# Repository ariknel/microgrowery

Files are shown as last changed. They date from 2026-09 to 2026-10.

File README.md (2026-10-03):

<p align="center">
  GrowBox Cabinet
</p>

<h1 align="center">🌱 GrowBox</h1>

<p align="center">
  Open-source USB-C powered smart microgrowery<br/>
  ESP32-S3 hub · 87W LED panel · WiFi dashboard · Camera streaming · USB-C PD
</p>

<p align="center">
  
  
  
  
</p>

---

## Table of Contents

- [Overview](#overview)
- [Cabinet](#cabinet)
- [PCB Boards](#pcb-boards)
- [Web Dashboard](#web-dashboard)
- [Camera Feed](#camera-feed)
- [Features](#features)
- [Grow Schedule Recommendations](#grow-schedule-recommendations)
- [Build & Technical Reference](BUILD.md)
- [Bill of Materials](BOM.md)
- [License](#license)

---

## Overview

GrowBox is a fully custom USB-C powered microgrowery designed to fit under a desk. The controller drives an 87W warm white LED grow panel, controls intake and exhaust ventilation fans, monitors temperature and humidity, streams a live camera feed, and serves a local web dashboard — all from a single USB-C cable.

Everything is custom designed: four separate PCBs, ESP32-S3 firmware in bare C using ESP-IDF, and a self-contained HTML dashboard served directly from the microcontroller.

<p align="center">
  Cabinet open showing plants
</p>

**Key specs at a glance:**

| Parameter | Value |
|---|---|
| Input power | USB-C PD 20V via FUSB302 |
| Max LED power | 87W (80× warm white LEDs) |
| LED panel | 4× boards in a grid |
| Cabinet size | 600 × 450 × 720mm (external) |
| MCU | ESP32-S3 bare SoC, 8MB NOR flash |
| Connectivity | WiFi 802.11 b/g/n, mDNS `growbox.local` |
| Environment sensor | AHT20 temperature + humidity |
| Camera | ESP32-CAM MJPEG stream |
| Fan control | 2× PWM fans, independent speed |

---

## Cabinet

Constructed from 12mm MDF, interior walls painted white for light distribution. A DIY activated carbon filter with a 120mm exhaust fan handles odor control.

<p align="center">
  Cabinet front closed
  &nbsp;&nbsp;
  Cabinet front open
</p>

<p align="center">
  Interior top view showing LED panel
  &nbsp;&nbsp;
  Interior side view showing fans and filter
</p>

```
External:   600 × 450 × 720mm  (W × D × H)
Internal:   576 × 426 × 696mm  (external minus 2× 12mm MDF wall per axis)
Fan intake:  120mm, bottom-right panel
Fan exhaust: 120mm, top-right panel
Carbon filter: 3D printed housing, 80mm activated carbon bed, inline on exhaust
```

<p align="center">
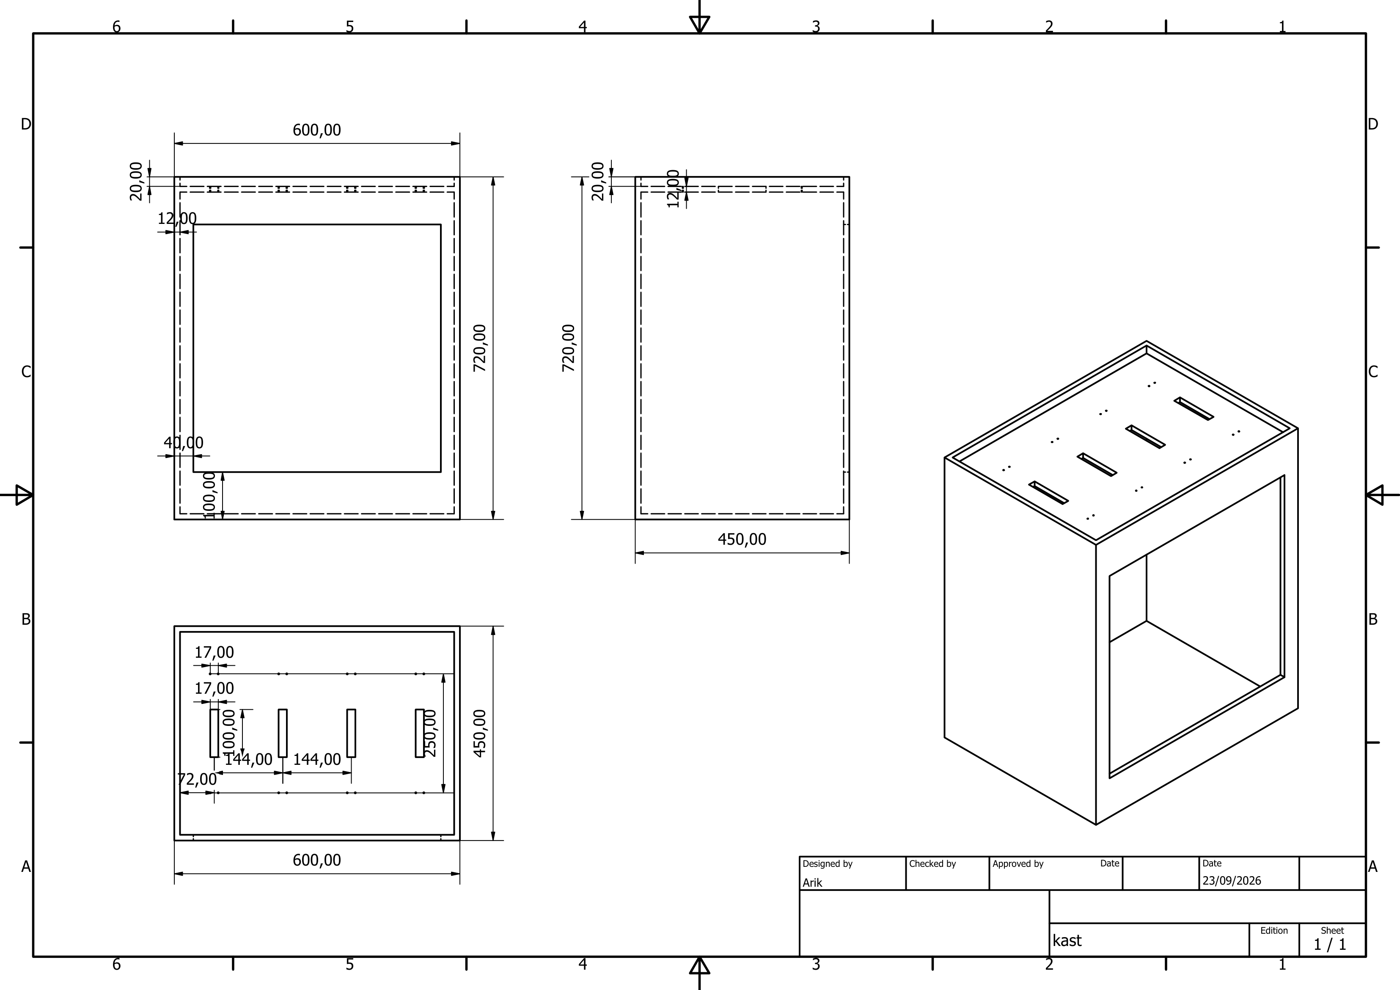
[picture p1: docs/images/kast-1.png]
Cabinet technical drawing
  
</p>

---

## PCB Boards

Four custom PCBs, designed in KiCad and manufactured at JLCPCB. Full GPIO pinout, connector tables and component values live in [BUILD.md](BUILD.md).

### 1. Main Hub Board

The brain of the system — ESP32-S3, FUSB302 PD sink negotiation, AP63203 3.3V regulator, 8MB flash, and JST connectors for every other board and peripheral.

<p align="center">
  Hub board top
  &nbsp;&nbsp;
  Hub board bottom
</p>

<p align="center">
  Hub board KiCad 3D render front
  &nbsp;&nbsp;
  Hub board KiCad 3D render back
</p>

<p align="center">
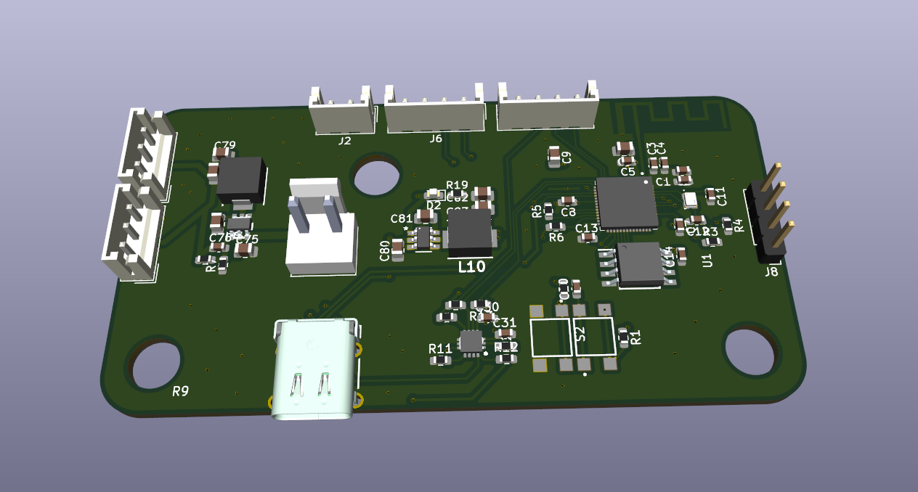
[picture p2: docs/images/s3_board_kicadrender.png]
Hub board KiCad 3D render, angled view showing USB-C, connectors and the ESP32-S3 module
  
</p>
<p align="center">
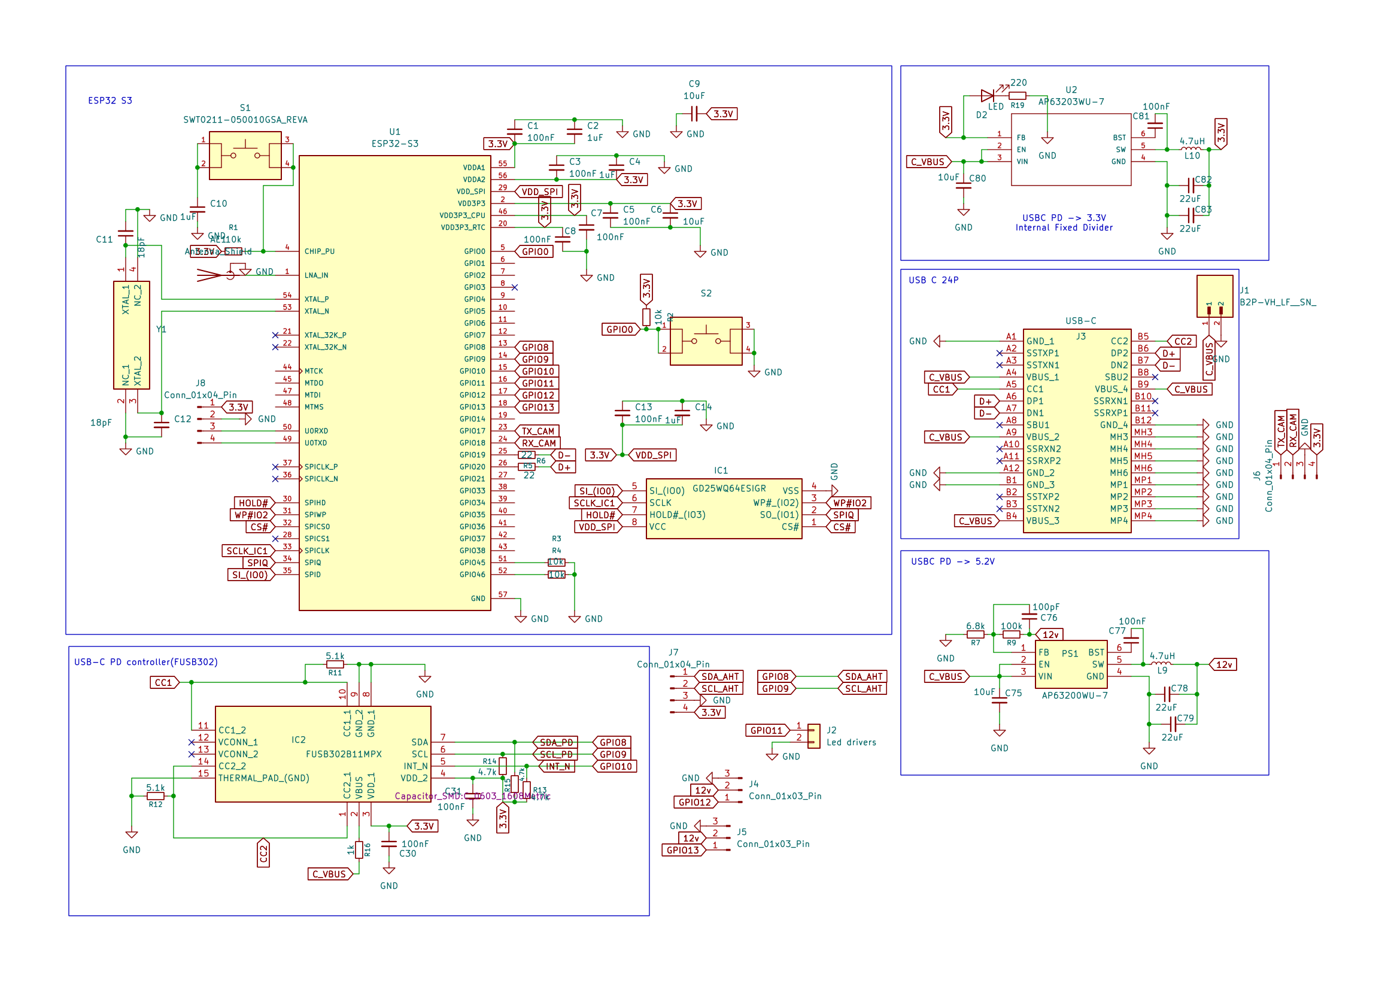
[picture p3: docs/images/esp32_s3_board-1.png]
Hub board full schematic — ESP32-S3, FUSB302 PD, USB-C, buck regulators
  
</p>

### 2. LED Driver Board

One of four identical boards — 4× TX6120 constant-current drivers each, powering 4 strings of 5 LEDs (~21.8W per board, ~87W across all four).

<p align="center">
  Driver board top assembled
  &nbsp;&nbsp;
  Driver board bottom
</p>

<p align="center">
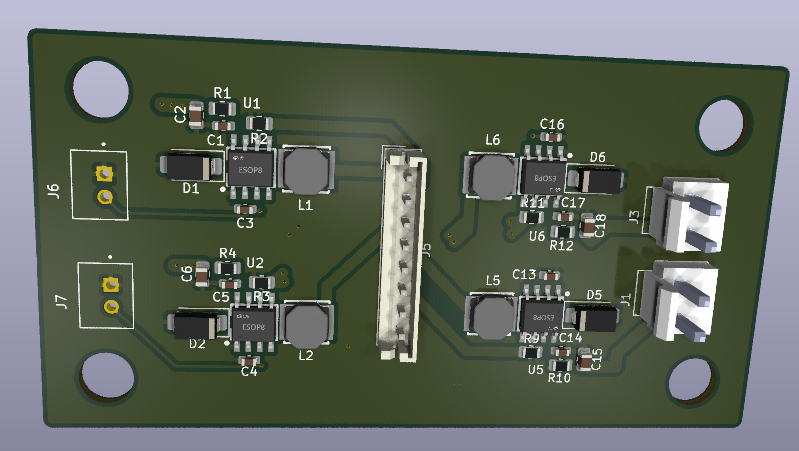
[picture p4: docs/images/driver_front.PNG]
Driver board KiCad 3D render
  
  &nbsp;&nbsp;
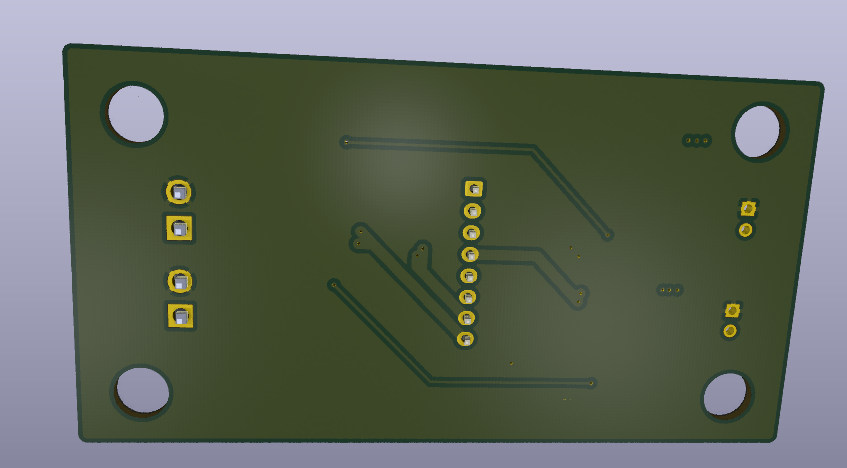
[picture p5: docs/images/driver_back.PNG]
Driver board KiCad 3D render back
  
</p>

<p align="center">
  All 4 driver boards side by side
</p>

### 3. LED Panel Board

One of four identical boards — 20× XL-3030WWC-1W-3V warm white LEDs each (80 total), single-layer FR4 with an aluminum bottom layer for heat spreading.

<p align="center">
  LED board not powered
  &nbsp;&nbsp;
  LED board powered on
</p>

<p align="center">
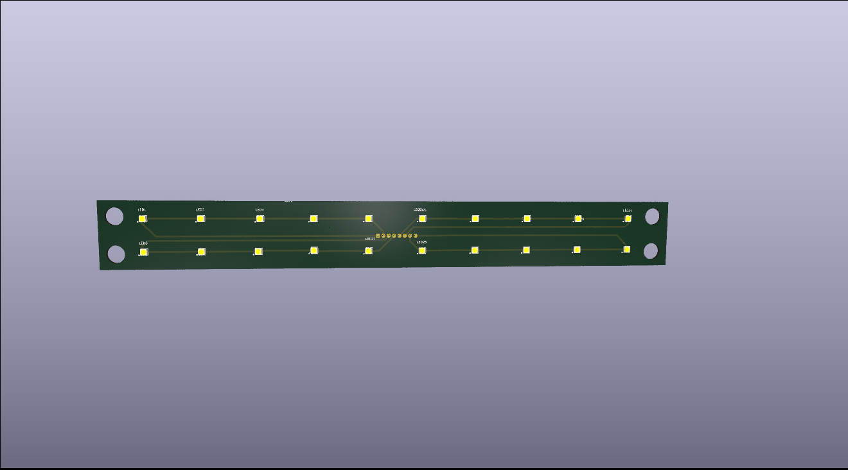
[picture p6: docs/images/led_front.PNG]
LED board KiCad 3D render
  
  &nbsp;&nbsp;
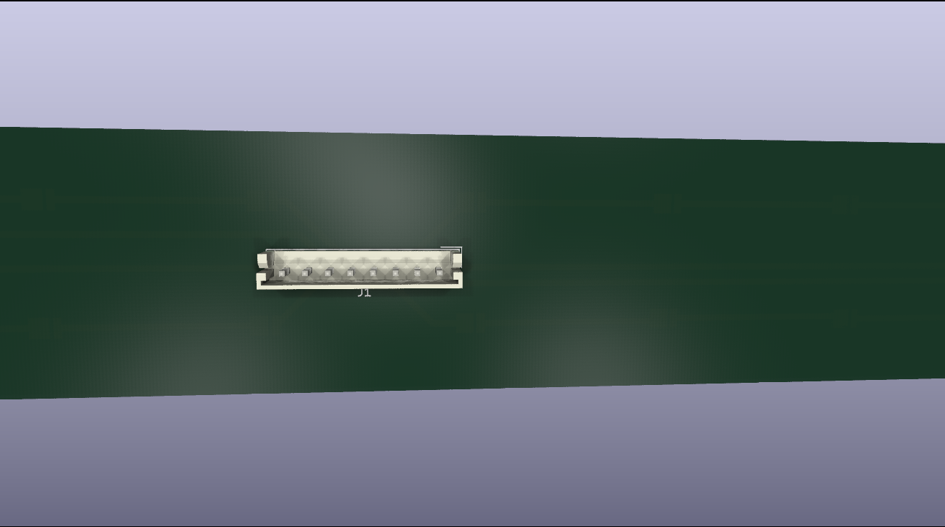
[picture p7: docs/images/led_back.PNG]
LED board back showing copper pour and aluminum bottom layer
  
</p>

<p align="center">
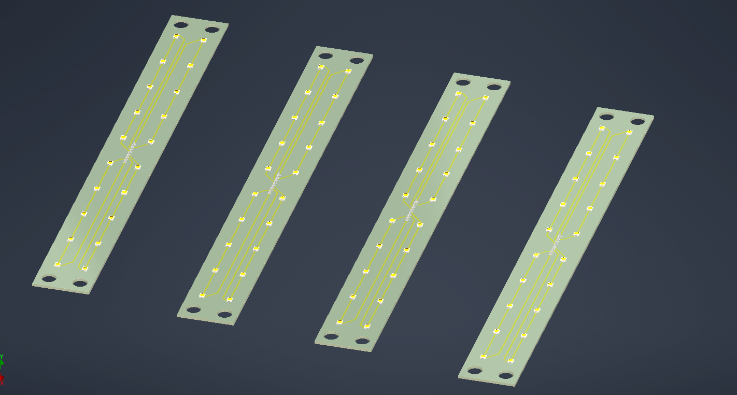
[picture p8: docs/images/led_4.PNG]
All 4 LED boards assembled in 2x2 arrangement
  
</p>
<p align="center">
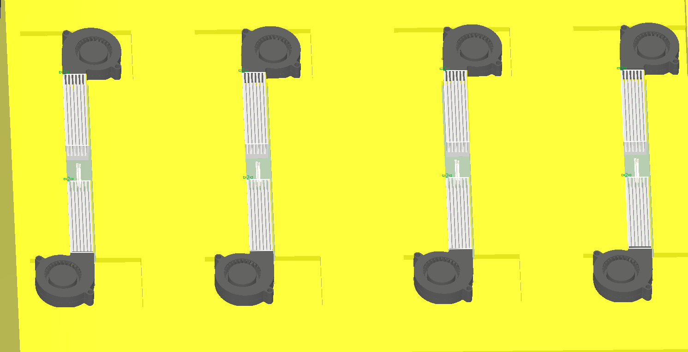
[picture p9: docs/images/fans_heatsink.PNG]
8x 5015 24dB blower fans, one per heatsink, each on its own short duct — 2 fans per LED board, 4 boards total
  
</p>

At 21.76W per board on an 85×55mm footprint, passive cooling alone isn't
enough to sustain full brightness — each board got 2× extruded aluminum
heatsinks, each with its own dedicated 5015 blower (24dB) on a short
individual duct: 8 fans total across the 4 boards, one per heatsink rather
than one fan shared across both. Estimated safe continuous power: ~4W bare
board, ~11W with heatsinks only, full 87W-panel brightness (100%) with the
fans running. Full thermal model and assumptions:
[BUILD.md#thermal-analysis--led-board-cooling](BUILD.md#thermal-analysis--led-board-cooling).

<p align="center">
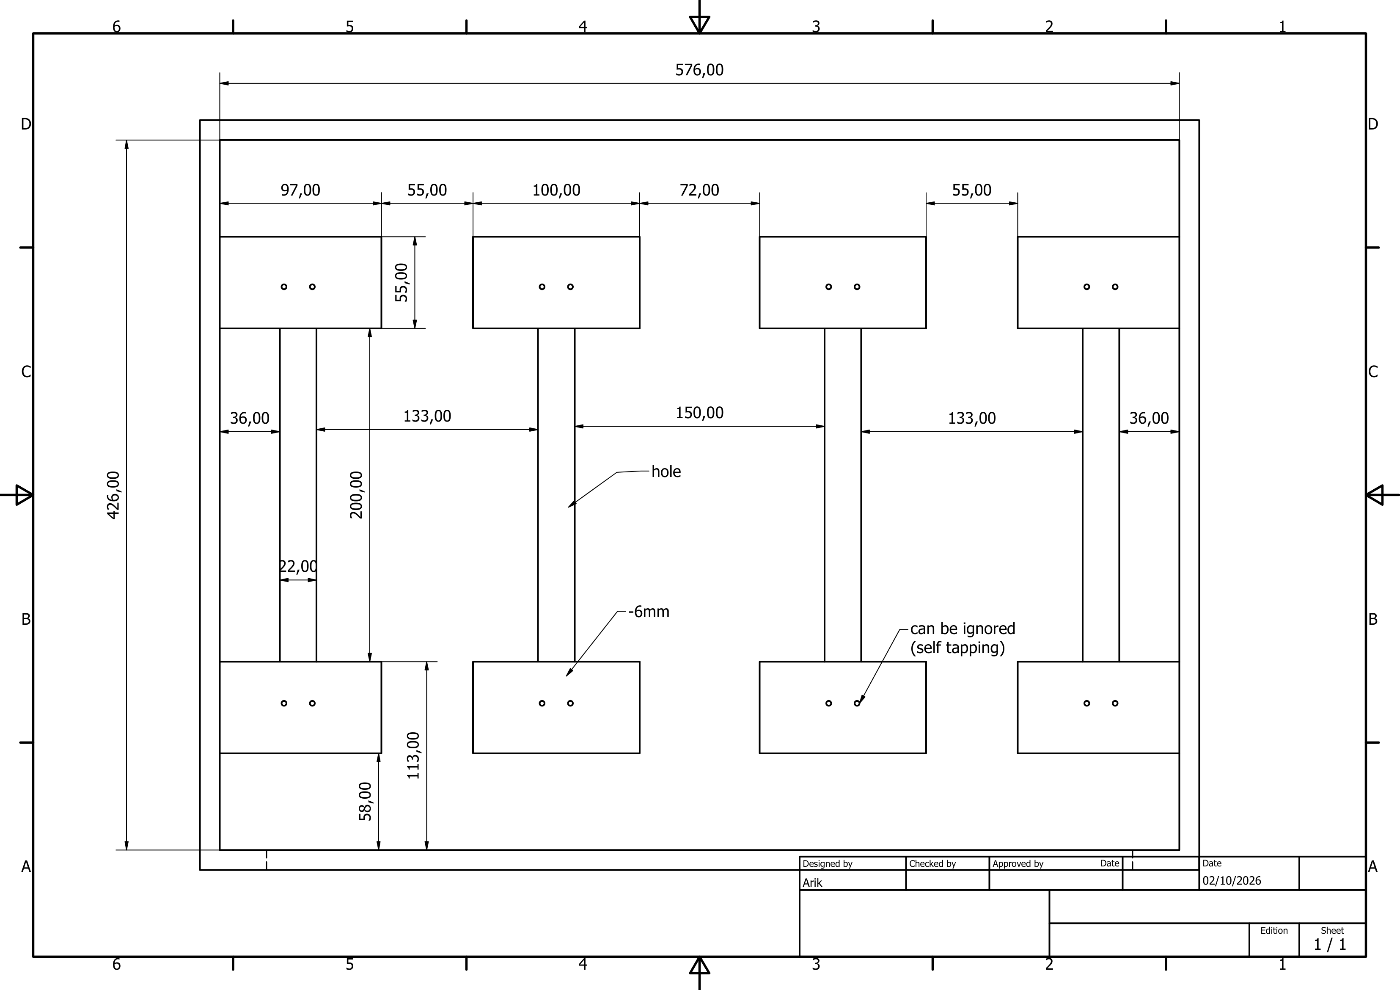
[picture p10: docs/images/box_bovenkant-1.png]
Top panel technical drawing — 576x426mm, 4 columns of 2 heatsink mounting pads each
  
</p>

The 8 fan cutouts aren't cut into the top panel drawing yet. Proposed
placement: centered on each of the 8 existing heatsink mounting pads shown
above (one column per LED board, top and bottom pad = top and bottom
heatsink), sized to a generic 50×50mm blower footprint — the real 5015's
exact mounting pattern still needs to be confirmed against its datasheet
before cutting. Fan control itself is a separate dedicated board — see
[fan_controller/](fan_controller/).

### 4. Sensor Board

A minimal standalone board carrying just the AHT20 temperature/humidity sensor, connected to the hub over a 4-pin I2C cable. Mounted mid-height on the cabinet wall, away from heat sources, for accurate ambient readings.

<p align="center">
  Sensor board top
  &nbsp;&nbsp;
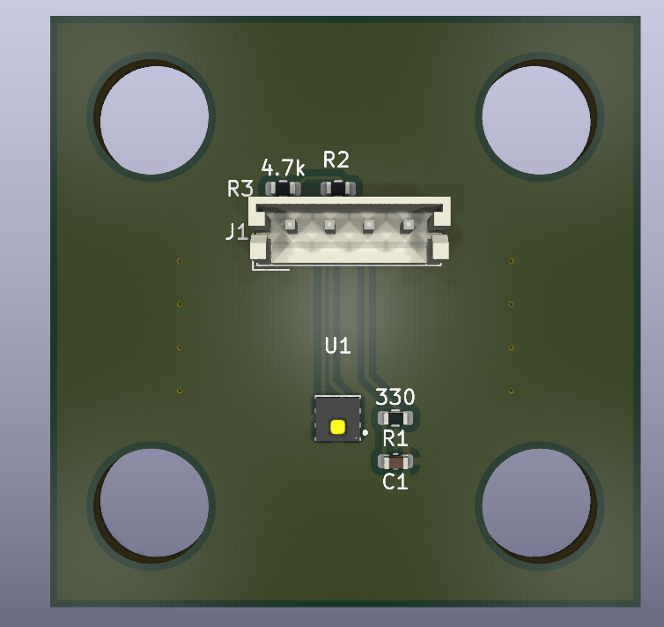
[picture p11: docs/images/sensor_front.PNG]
Sensor board KiCad 3D render
  
</p>

---

## Web Dashboard

A single self-contained HTML file served directly from ESP32-S3 flash — no internet connection required. Access it at `http://growbox.local` from any device on the same WiFi network.

<p align="center">
  Full dashboard screenshot
</p>
<p align="center">
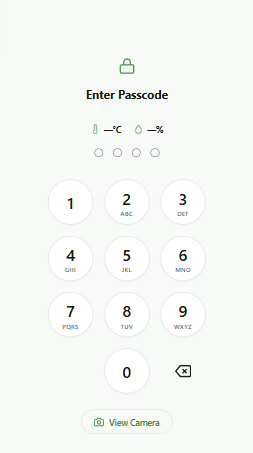
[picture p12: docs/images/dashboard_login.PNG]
Dashboard Mobile Login Page
  
</p>

<p align="center">
  Dashboard on mobile
  &nbsp;&nbsp;
  Dashboard with camera feed active
  &nbsp;&nbsp;
  Dashboard light schedule panel
</p>

| Panel | Description |
|---|---|
| Camera feed | Live MJPEG stream from ESP32-CAM, tap to enable/disable |
| Temperature / humidity | Live readings, session min/max |
| LED brightness | Slider 0–100% with live watt estimation |
| Fan control | Independent intake and exhaust sliders |
| Light schedule | On/off time pickers, 24h visual timeline, enable toggle |
| System status | WiFi RSSI, uptime, PD status, free heap, grow day counter |
| Power summary | Estimated total wall draw |

---

## Camera Feed

The ESP32-CAM mounts on the interior cabinet wall via a 3D printed bracket, angled downward to cover the full plant canopy, connected to the hub over a 4-wire UART cable. It streams on demand only — power-saving start/stop commands are sent as the dashboard opens and closes the feed. Protocol details in [BUILD.md](BUILD.md).
<p align="center">
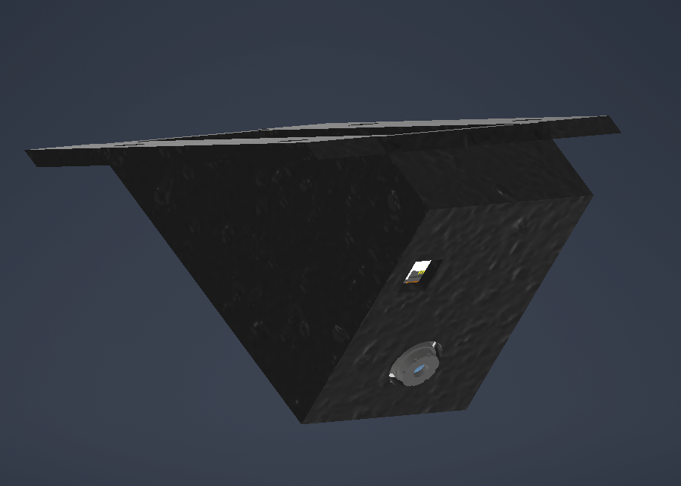
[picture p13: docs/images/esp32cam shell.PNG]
ESP32-CAM Mount CAD
  
</p>
<p align="center">
  ESP32-CAM mounted inside cabinet
</p>

<p align="center">
  Camera feed showing plants
</p>

---

## Features

- **USB-C PD negotiation** — full FUSB302 driver written from scratch in C. Requests 20V fixed PDO, handles Source_Capabilities, Accept, PS_RDY. Retries every 30 seconds on failure, renegotiates on cable disconnect
- **LED brightness control** — 0–100% PWM via LEDC at 25kHz. Smooth 5-minute sunrise/sunset ramp on schedule transitions. Persisted to NVS
- **Light schedule** — configurable on/off time, SNTP sync, Europe/Brussels timezone, grow day counter from first boot
- **Fan control** — independent intake and exhaust speed 0–100%
- **Environment monitoring** — AHT20 polled every 10 seconds, session min/max for temperature and humidity
- **Camera integration** — ESP32-CAM sends IP over UART on boot, hub proxies MJPEG to browser on demand
- **Web dashboard** — self-contained single HTML file, mobile responsive, no internet dependency
- **WiFi provisioning** — SoftAP captive portal on first boot, saves credentials to NVS, connects automatically after
- **mDNS** — accessible at `growbox.local`, no IP address needed

---

## Grow Schedule Recommendations

| Crop | Light on | Light off | Hours | Brightness |
|---|---|---|---|---|
| Seedlings (all) | 06:00 | 22:00 | 16h | 40% |
| Vegetative cannabis | 06:00 | 00:00 | 18h | 70% |
| Autoflower full cycle | 06:00 | 00:00 | 18h | 75% |
| Photoperiod flowering | 08:00 | 20:00 | 12h | 85% |
| Peppers / chili | 06:00 | 22:00 | 16h | 65% |
| Herbs / lettuce | 06:00 | 22:00 | 16h | 55% |
| Microgreens | 06:00 | 22:00 | 16h | 45% |

Power draw at each brightness level: see [BUILD.md](BUILD.md#power-budget).

---

## More

- **[BUILD.md](BUILD.md)** — GPIO pinout, wiring, connectors, NVS config, task structure, project layout, and build/flash instructions
- **[BOM.md](BOM.md)** — parts list and cost breakdown

---

## License

MIT License — see [LICENSE](LICENSE) file.

---

<p align="center">
  Made by Arik · IoT & Electronics Engineering Student · Belgium
</p>

<p align="center">
  Plants growing inside the cabinet
</p>

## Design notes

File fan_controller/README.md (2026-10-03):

# GrowBox Fan Controller

Arduino Nano sketch, independent of the ESP32-S3 hub and ESP32-CAM — see
[../BUILD.md#thermal-analysis--led-board-cooling](../BUILD.md#thermal-analysis--led-board-cooling)
for why the LED heatsinks need active cooling in the first place, and
[../README.md](../README.md) for the cabinet-level overview.

## What it does

4 independent zones, one per LED board. Each zone has its own NTC
thermistor — mounted directly on that board's PCB, not on a heatsink, so
it reads that specific board's temperature rather than general cabinet
airflow — and its own MOSFET switching that board's 2 fans together. A
board running hotter than the other 3 only speeds up its own 2 fans, not
all 8; each board's cooling is independent of the others.

Runs standalone on purpose: fan cooling keeps working even if the hub
reboots, the camera hangs, or WiFi is down — none of that affects this
board, which shares no pins or power with either. Cooling doesn't depend
on the hub hearing from it either — see "Telemetry to the hub" below.

## Telemetry to the hub

Every `REPORT_INTERVAL_MS` (2s), the Nano sends one line over its
hardware Serial (pins 0/RX, 1/TX) to the hub's `J14` UART0 debug header:

```json
{"temps":[23.4,25.1,22.8,24.0],"duty":[90,0,120,255]}
```

**Needs a voltage divider — the Nano is 5V logic, the ESP32-S3's GPIOs
are 3.3V max.** Don't wire Nano TX straight to the hub's RX pin.

```
Nano TX ---[10k]---+--- hub RX (J14)
                    |
                  [15k]
                    |
                   GND
```

`5V × 15k/(10k+15k) = 3.0V` at the junction — safely above the ESP32's
logic-high threshold (~2.48V) and comfortably under its 3.3V max. The
divider's output impedance (~6kΩ) is irrelevant against a GPIO's input
capacitance at 9600 baud, so no signal integrity concern either.

A faulted sensor reports as `null` rather than a made-up number. This is
**send-only** — the Nano's RX isn't wired to anything, and the hub never
talks back. Nothing about fan control depends on the hub receiving this;
it's read-only visibility, not a control input. Unplug it before
re-uploading the sketch over USB, same as unplugging anything else wired
to pins 0/1.

The hub parses this in `firmware/main/uart_fan.c` and stores it in
`g_state.fan_ctrl_*`, exposed read-only on `GET /api/status` under
`fan_controller`, and shown on the dashboard's "LED Cooling" card
(protected, after login — not on the public lock-screen preview). A
`null` temp entry shows as "fault" instead of a number; the card shows an
"offline" notice until the first line has ever arrived (it doesn't go
back to offline if the Nano later stops sending — no staleness timeout).

## Fan curve (tune these against a real thermocouple)

| Board temp | That board's 2 fans |
|---|---|
| < 35°C | off |
| 35°C – 55°C | ramps 35%–100% |
| ≥ 55°C | full speed |
| that zone's sensor open/shorted | that zone fails to full speed; other 3 zones unaffected |

Thresholds are `#define`s at the top of `fan_controller.ino` — the
35°C/55°C numbers are starting points, not measured values; see the
thermal analysis in BUILD.md for why (no datasheet thermal-resistance
data exists for these exact parts, so nothing in that chain is lab
measured yet).

## Noise

Each 5015 blower is rated ~24-28dB. Sound pressure from N identical
incoherent sources adds `10*log10(N)` dB, so all 8 fans (4 boards × 2
each) at full speed simultaneously is roughly a 9dB bump over one fan
alone — about **33-37dB combined**, treating all 8 as equidistant (a
rough worst-case estimate, not a measurement). Because the 4 boards share
the same dashboard brightness setting, they'll usually run close to the
same temperature and ramp up together in practice, even though each
zone's speed is computed independently — the "independent zones" design
is mainly about catching the board that's hotter than the others (worse
airflow, a bad thermal pad, etc.), not about normal operation being wildly
uneven. At low brightness all 4 zones stay off or quiet.

## Wiring (×4, one set per zone)

<p align="center">
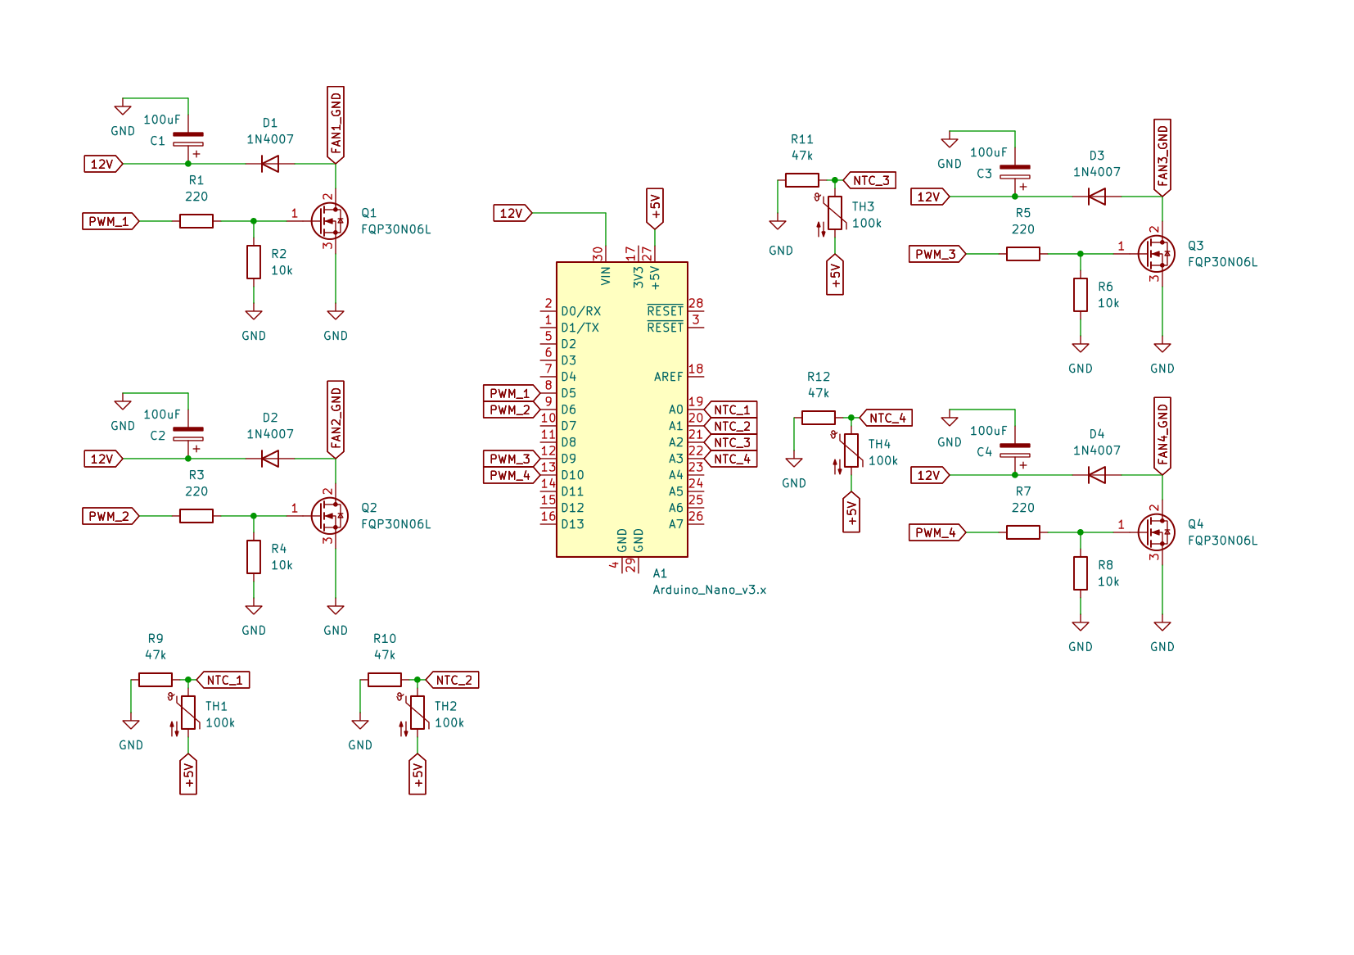
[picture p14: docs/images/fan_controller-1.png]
Fan controller schematic — Arduino Nano, 4x NTC divider + 4x MOSFET switching channel
  
</p>

```
+5V ---[TH: 100k NTC]---+---[R: 47k]--- GND      (NTC on the LED board's own PCB)
                        |
                        Nano Ax

Nano PWM pin ----------- MOSFET gate (direct — FQP30N06L is logic-level, no series resistor)
                         gate --[10k pulldown to GND]
MOSFET source -> GND
MOSFET drain  -> FANn_GND (that board's 2 fans' common return)
12V ---[220R]--+-- 1N4007 (cathode) -- FANn_GND     (snubber/flyback, clamps the
               |                                     switching spike back toward
             [100uF to GND]                          the rail instead of across the MOSFET)
Fans' + -> 12V rail (same one already on the main hub board)
```

| Zone (board) | NTC pin | MOSFET gate pin | Snubber R / D / C | Gate pulldown |
|---|---|---|---|---|
| 1 | A0 (NTC_1) | D5 (PWM_1) | R1 220Ω / D1 1N4007 / C1 100µF | R2 10k |
| 2 | A1 (NTC_2) | D6 (PWM_2) | R3 220Ω / D2 1N4007 / C2 100µF | R4 10k |
| 3 | A2 (NTC_3) | D9 (PWM_3) | R5 220Ω / D3 1N4007 / C3 100µF | R6 10k |
| 4 | A3 (NTC_4) | D10 (PWM_4) | R7 220Ω / D4 1N4007 / C4 100µF | R8 10k |

NTC divider resistors: R9 (zone 1), R10 (zone 2), R11 (zone 3), R12
(zone 4), all 47kΩ. MOSFETs: Q1–Q4, FQP30N06L (TO-220, logic-level gate —
safe to drive straight from the Nano's 5V PWM output, which is why there's
no gate series resistor in this design).

Keep this board-to-pin mapping consistent with how the boards are
physically labeled in the cabinet — otherwise "board 3 running hot" on
the serial log points at the wrong board.

The gate pull-down on each MOSFET matters: without it, that gate floats
during Nano power-on/reset (before `setup()` runs) and can sit in a lossy
partially-on state that heats up the MOSFET itself — not just a lost few
hundred ms of cooling. The 220Ω/1N4007/100µF network per channel clamps
the inductive switching spike from the fan motor back toward the 12V rail
(through the resistor, which limits clamp current) instead of letting it
ring across the MOSFET's drain-source junction, and the 100µF cap locally
decouples that channel's share of the 12V rail.

NTC part: HNTC-104F3950FB, 100kΩ @25°C, B=3950, ±1% ([LCSC C52204613](https://lcsc.com/product-detail/C52204613.html)),
paired with a 47kΩ series resistor — update `SERIES_RESISTOR_OHMS` in the
sketch if the real build ends up using a different series value. If you
ever swap to a different NTC part, double-check its Beta rating before
reusing these defaults; a wrong Beta/R25 shifts the whole curve without
giving any obvious sign that it's wrong.

## Flashing

Stock Arduino IDE, board "Arduino Nano", no external libraries. Open
`fan_controller.ino` and upload — same as any Nano sketch.

## Known gaps

- Thresholds are unverified placeholders — needs real thermocouple
  validation on each board, same caveat as the rest of the thermal
  analysis this design is based on.
- No tachometer feedback (fans' 3rd wire, if present, isn't read) — the
  controller can't detect a stalled or disconnected fan on a given zone,
  only react to that zone's temperature.
- An NTC mounted on the PCB (rather than on the heatsink itself) reads
  board temperature, which tracks junction temperature more directly but
  lags heatsink temperature slightly — fine for this fan curve's purpose,
  worth knowing if you ever compare readings against the heatsink-surface
  numbers in the BUILD.md thermal analysis.

Schematic source: [docs/Schematics/fan_controller.pdf](../docs/Schematics/fan_controller.pdf).

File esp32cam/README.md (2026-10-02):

# GrowBox Camera Firmware

ESP-IDF firmware (bare C, no Arduino) for the common AI-Thinker ESP32-CAM
board — the camera half of the [GrowBox](../README.md) build. Talks to the
hub over a dedicated UART link; the hub proxies the stream to the
dashboard. Same build method as the hub firmware: Docker, no local
toolchain install needed.

## What it does

1. Has no network connectivity at all — no WiFi hardware is configured on
   this board. Everything it does (video out, commands in) goes over the
   dedicated UART link to the hub, so there's no IP address anywhere in
   this picture.
2. Announces it's up and ready over UART once at boot: `{"ready":true}\n`.
   The hub uses this purely as a liveness signal to know the camera board
   has booted and is listening.
3. Listens on that same UART for commands from the hub:
   - `{"cmd":"stream","state":1}` — start streaming (~3fps QVGA JPEG)
   - `{"cmd":"stream","state":0}` — stop
   - `{"cmd":"snapshot"}` — capture and send exactly one frame
   - `{"cmd":"flash"}` — turn on the onboard LED (GPIO4) for 10s, then
     auto-off; re-triggering while already on just extends the window
4. Sends each JPEG frame framed as the hub expects:
   `0xFF 0xD8 [4-byte big-endian length] [JPEG bytes] 0xFF 0xD9`

No local web server, no SD card, no direct connection from the browser —
the hub is the only thing this board talks to.

## Hardware

**UART link to the hub** (separate from the programming UART):

| Signal | GPIO | Baud |
|---|---|---|
| TX | 14 | 921600 |
| RX | 15 | 921600 |

GPIO1/GPIO3 (UART0) are *not* used for this link — those are only touched
by the external USB-serial programmer during the one-time flash. Wire
GPIO14/15 to the hub's UART1 (GPIO17/18) permanently; the programmer gets
unplugged after flashing and isn't part of the running system.

**Camera pins** — standard AI-Thinker mapping, see `main/camera_pins.h`.
Double-check against your board's silkscreen if you're on a less common
clone; pin assignment is the single most common source of
`esp_camera_init()` failures.

## Flashing (one-time, needs the external programmer)

AI-Thinker boards have no native USB. You need a USB-to-serial adapter
(FTDI, CP2102, etc.) wired to the board's UART0 (GPIO1 TX, GPIO3 RX, 5V,
GND), **plus GPIO0 pulled to GND** to enter download mode:

1. Wire the adapter: adapter TX → board RX (GPIO3), adapter RX → board TX
   (GPIO1), 5V, GND.
2. Bridge GPIO0 to GND (jumper wire or button, if your board has one).
3. Power-cycle or press reset — the board is now in download mode.
4. Flash (see below).
5. Remove the GPIO0-to-GND bridge, power-cycle again — it boots normally.
6. Unplug the external programmer. From here on the board only talks to
   the hub over GPIO14/15.

## Build

No config step needed — this board has no network settings at all (see
"What it does" above).

```bash
docker compose run --rm build
# or:
scripts/build.sh
```

First build needs internet access once — `main/idf_component.yml` pulls
in Espressif's `esp32-camera` component from the registry, which isn't
bundled with core ESP-IDF.

## Flash

Recommended: from the host with plain esptool (`pip install esptool`),
after wiring up as described above:

```bash
scripts/flash.sh /dev/ttyUSB0     # or COM5 on Windows
```

Or through Docker with USB passthrough set up (see the hub firmware's
README for the per-OS notes — same deal here):

```bash
docker compose run --rm flash
```

## Monitor

```bash
scripts/monitor.sh /dev/ttyUSB0
# or, with USB passthrough:
docker compose run --rm monitor
```

## VS Code dev container

Same pattern as the hub: open this folder in VS Code and accept "Reopen in
Container" — `idf.py build` then works straight from the integrated
terminal, no local toolchain needed. The container deliberately has no USB
device access (a hard-coded device mount breaks container creation outright
on Windows, where Docker Desktop has no real `/dev` to bind from), so flash
and monitor from the **host** instead, same as above
(`scripts/flash.sh` / `scripts/monitor.sh`), or from a separate terminal —
not the devcontainer's own.

## Known gaps

- Pin mapping is the standard AI-Thinker layout, transcribed from the
  widely-used reference config — not yet bench-tested against real
  hardware.
- The onboard flash LED (GPIO4) is driven directly — see "What it does"
  below. That pin also doubles as an SD card data line on this board, so
  using SD alongside it isn't an option (not that anything here needs SD).
- Frame rate (~3fps) is a fixed delay between captures, not adaptive to
  actual encode time — fine for a grow-cabinet monitor, not tuned for
  anything faster.

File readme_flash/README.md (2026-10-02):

<<<<<<< HEAD
# Microgrowery Controller

ESP32-S3 firmware for a DIY grow-cabinet controller (USB-PD power intake,
LED + fan control, light schedule, AHT20 temp/humidity, ESP32-CAM feed),
paired with the dashboard in `dashboard.html`.

**What Docker does and doesn't do here:** it builds the firmware in a
reproducible container (Espressif's official `espressif/idf` image) so
you don't need the ESP-IDF toolchain installed on your machine. It does
**not** run the firmware — there's no OS on the ESP32-S3 for a container
to sit on. The container produces a `.bin`; that binary is what gets
flashed onto and runs directly on the chip's own silicon.

## Layout

```
firmware/           ESP-IDF project (this is what gets built/flashed)
  main/              all C sources, plus dashboard.html embedded into the binary
  partitions.csv     custom partition table for the 8MB flash
  sdkconfig.defaults  target/flash/console defaults
.devcontainer/       VS Code dev container config (recommended workflow)
Dockerfile           image the dev container and docker-compose both use
docker-compose.yml   alternative to the dev container, for use outside VS Code
scripts/             host-side convenience wrappers (used by the alternative path)
dashboard.html       the browser dashboard (also copied into firmware/main/)
```

If you edit `dashboard.html` at the repo root, re-copy it into
`firmware/main/dashboard.html` before rebuilding — it's embedded into the
binary at build time via `EMBED_TXTFILES`, not read from disk at runtime.

---

## One-time setup

1. Install **Docker Desktop**, with the **WSL2** backend enabled
   (Settings → General → "Use the WSL 2 based engine"). This is the
   default on a fresh install.
2. Install the **Dev Containers** extension in VS Code
   (`ms-vscode-remote.remote-containers`).
3. **Windows only** — the ESP32-S3 shows up as a USB device to Windows,
   but Docker Desktop's containers run inside WSL2, which doesn't see
   Windows USB devices by default. [usbipd-win](https://github.com/dorssel/usbipd-win)
   bridges that gap, once per device:
   ```powershell
   winget install usbipd
   ```
   Leave this step here for now — you'll run the actual attach command
   in step 2 below, *after* plugging the board in.

That's the whole one-time setup. Everything below is the normal
day-to-day loop.

---

## Everyday workflow

### 1. Plug in the board

Connect the ESP32-S3 to your PC over USB.

**Windows only** — share it into WSL2 (repeat this each time you
replug the board or reboot Windows; it does *not* persist):
```powershell
usbipd list
# find the line for your board, note its BUSID, e.g. 1-4
usbipd bind --busid 1-4
usbipd attach --wsl --busid 1-4
```

Linux and macOS: nothing to do here, skip to step 2.

### 2. Open the project in VS Code

Open the repo root folder in VS Code. A popup appears in the
bottom-right: **"Reopen in Container"** — click it.

*(First time only: this builds the image, which takes a few minutes.
Every time after that, it reuses the cached image and starts in a few
seconds. If you miss the popup, open the Command Palette —
`Ctrl+Shift+P` — and run **Dev Containers: Reopen in Container**.)*

Once it's open, VS Code's integrated terminal is now a shell *inside*
the container, already sitting in `firmware/`, with `idf.py` on PATH
and the board's serial port visible. This is the only terminal you
need from here on — no more `docker compose run`, no separate WSL
window.

### 3. Build

```
idf.py build
```

### 4. Flash

Find the port name first (only needed once per session — it won't
change until you unplug/replug):
```
ls /dev/ttyUSB* /dev/ttyACM*
```
Then:
```
idf.py -p /dev/ttyUSB0 flash
```
(swap in whichever port `ls` showed you.)
idf.py flash
or
 idf.py -p PORT flash
or
 python -m esptool --chip esp32 -b 460800 --before default_reset --after hard_reset write_flash --flash_mode dio --flash_size 4MB --flash_freq 40m 0x1000 build/bootloader/bootloader.bin 0x8000 build/partition_table/partition-table.bin 0x10000 build/growbox_cam.bin
or from the "/workspaces/microgrowery/esp32cam/build" directory
 python -m esptool --chip esp32 -b 460800 --before default_reset --after hard_reset write_flash "@flash_args"
root@1da86854c589:/workspaces/microgrowery/esp32cam# 
### 5. Monitor

```
idf.py -p /dev/ttyUSB0 monitor
```
Ctrl+] exits the monitor.

### 6. The rebuild loop

Once you've done steps 3–5 once, day-to-day is just:
```
idf.py build flash monitor
```
— builds, flashes, and drops straight into the serial monitor in one
command, all from the same VS Code terminal.

---

## Alternative: without VS Code

If you'd rather not use the dev container (scripted builds, CI, a
different editor), `docker-compose.yml` does the same build in one shot
from any terminal:

```
docker compose run --rm build
```

Flashing this way needs the same USB passthrough as above, and Docker
Desktop's device passthrough has real per-OS limits:

- **Linux**: works directly — `docker compose run --rm flash`
  (set `PORT=/dev/ttyACM0` etc. if it's not `/dev/ttyUSB0`).
- **Windows**: do the `usbipd attach` step above from a WSL2 shell, then
  `PORT=/dev/ttyUSB0 docker compose run --rm flash` from that same shell.
- **macOS**: not possible — Docker Desktop on Mac has no generic USB
  passthrough. Use `scripts/flash.sh` instead (below).

For macOS, or anytime you don't want to deal with passthrough at all,
flash from the host directly with plain `esptool` (`pip install esptool`
— a small pure-Python package, not the full toolchain):
```
scripts/flash.sh /dev/ttyUSB0     # Linux/macOS
scripts/flash.sh COM5             # Windows, from PowerShell
```
And monitor with `pyserial` (`pip install pyserial`):
```
scripts/monitor.sh /dev/ttyUSB0
=======
<p align="center">
  <img src="docs/images/growbox_hero.jpg" alt="GrowBox Cabinet" width="800"/>
</p>

<h1 align="center">🌱 GrowBox</h1>

<p align="center">
  Open-source USB-C powered smart microgrowery controller.<br/>
  ESP32-S3 hub · 65W LED panel · WiFi dashboard · Camera streaming · USB-C PD
</p>

<p align="center">
  <img src="https://img.shields.io/badge/ESP--IDF-v5.x-blue"/>
  <img src="https://img.shields.io/badge/language-C-lightgrey"/>
  <img src="https://img.shields.io/badge/power-USB--C%20PD%2020V-green"/>
  <img src="https://img.shields.io/badge/license-MIT-brightgreen"/>
</p>

---

## Table of Contents

- [Overview](#overview)
- [Cabinet](#cabinet)
- [System Architecture](#system-architecture)
- [PCB Boards](#pcb-boards)
  - [1. Main Hub Board](#1-main-hub-board)
  - [2. LED Driver Board](#2-led-driver-board)
  - [3. LED Panel Board](#3-led-panel-board)
  - [4. Sensor Board](#4-sensor-board)
- [Web Dashboard](#web-dashboard)
- [Camera Feed](#camera-feed)
- [Wiring Overview](#wiring-overview)
- [Features](#features)
- [API Endpoints](#api-endpoints)
- [Project Structure](#project-structure)
- [FreeRTOS Task Structure](#freertos-task-structure)
- [NVS Configuration](#nvs-configuration)
- [Building and Flashing](#building-and-flashing)
- [ESP32-CAM Setup](#esp32-cam-setup)
- [Grow Schedule Recommendations](#grow-schedule-recommendations)
- [Bill of Materials](#bill-of-materials)
- [License](#license)

---

## Overview

GrowBox is a fully custom USB-C powered microgrowery controller designed to fit under a desk. It drives a 65W warm white LED grow panel, controls intake and exhaust ventilation fans, monitors temperature and humidity, streams a live camera feed, and serves a local web dashboard — all from a single USB-C cable.

Everything is custom designed: four separate PCBs, ESP32-S3 firmware in bare C using ESP-IDF, and a self-contained HTML dashboard served directly from the microcontroller.

<p align="center">
  <img src="docs/images/growbox_open_door.jpg" alt="Cabinet open showing plants" width="700"/>
</p>

**Key specs at a glance:**

| Parameter | Value |
|-----------|-------|
| Input power | USB-C PD 20V via FUSB302 |
| Max LED power | 65W (60× warm white LEDs) |
| LED panel size | 4× 85×55mm boards, 2×2 arrangement |
| Cabinet size | 380×380×850mm (external) |
| MCU | ESP32-S3 bare SoC, 8MB NOR flash |
| Connectivity | WiFi 802.11 b/g/n, mDNS growbox.local |
| Environment sensor | AHT20 temperature + humidity |
| Camera | ESP32-CAM MJPEG stream |
| Fan control | 2× PWM fans, independent speed |

---

## Cabinet

The cabinet is constructed from 18mm MDF with a full-front door sealed with EPDM weatherstripping and magnetic latches. Internal walls are lined with reflective Mylar film to maximize light distribution. A DIY activated carbon filter with a 120mm exhaust fan handles odor control.

<p align="center">
  <img src="docs/images/cabinet_front_closed.jpg" alt="Cabinet front closed" width="400"/>
  &nbsp;&nbsp;
  <img src="docs/images/cabinet_front_open.jpg" alt="Cabinet front open" width="400"/>
</p>

<p align="center">
  <img src="docs/images/cabinet_interior_top.jpg" alt="Interior top view showing LED panel" width="400"/>
  &nbsp;&nbsp;
  <img src="docs/images/cabinet_interior_side.jpg" alt="Interior side view showing fans and filter" width="400"/>
</p>

**Cabinet dimensions:**

```
External:   380 × 380 × 850mm  (W × D × H)
Internal:   342 × 342 × 814mm
Wall:       18mm MDF

LED panel:  mounted at top, 10mm clearance minimum to plants
Usable grow height: ~500mm (accounting for pot + light clearance)

Fan intake:  120mm, bottom-right panel
Fan exhaust: 120mm, top-right panel
Carbon filter: 3D printed housing, 80mm depth activated carbon bed,
               mounted inline on exhaust
```

<p align="center">
  <img src="docs/images/cabinet_dimensions.jpg" alt="Cabinet technical drawing" width="600"/>
</p>

---

## System Architecture

```
                        USB-C PD Charger (100W GaN)
                                  │
                                  │ 20V @ up to 5A
                                  ▼
                    ┌─────────────────────────────┐
                    │        MAIN HUB BOARD        │
                    │                              │
                    │  FUSB302 ──► 20V rail        │
                    │  ESP32-S3                    │
                    │  SY8120B ──► 3.3V logic      │
                    │  AHT20 sensor board (ext.)   │
                    │  ESP32-CAM (ext. via UART)   │
                    └──────────┬───────────────────┘
                               │
               ┌───────────────┼───────────────┐
               │               │               │
               ▼               ▼               ▼
        LED Board 1      LED Board 2     LED Board 3+4
       (3× TX6120)      (3× TX6120)     (3× TX6120 each)
       15 LEDs           15 LEDs         15 LEDs each
       ~16W              ~16W            ~16W each
```

All four LED driver boards receive:
- **20V power** via individual JST VH 2-pin cables (star topology from hub)
- **DIM_PWM signal** via 2-pin signal cable (daisy-chainable, milliamp level)

---

## PCB Boards

The project consists of four custom PCBs, all designed in KiCad and manufactured at JLCPCB.

---

### 1. Main Hub Board

> The brain of the system. Houses the ESP32-S3 bare SoC, FUSB302 PD negotiation, all power regulation, and JST connectors for every other board and peripheral.

<p align="center">
  <img src="docs/images/pcb_hub_top.jpg" alt="Hub board top" width="500"/>
  &nbsp;&nbsp;
  <img src="docs/images/pcb_hub_bottom.jpg" alt="Hub board bottom" width="500"/>
</p>

<p align="center">
  <img src="docs/images/pcb_hub_render_front.jpg" alt="Hub board KiCad 3D render front" width="500"/>
  &nbsp;&nbsp;
  <img src="docs/images/pcb_hub_render_back.jpg" alt="Hub board KiCad 3D render back" width="500"/>
</p>

**Key components:**

| Component | Part | Description |
|-----------|------|-------------|
| MCU | ESP32-S3 QFN-56 | Dual-core 240MHz, WiFi+BLE, USB JTAG |
| Flash | GD25WQ64ESIGR | 8MB NOR SPI flash, WSON-8 |
| PD controller | FUSB302UCX | USB-C PD sink, I2C controlled |
| 3.3V regulator | SY8120B | 26V input, 1A buck |
| USB-C receptacle | 16-pin SMD | Power + CC1/CC2 for FUSB302 + D+/D- for JTAG |
| Crystal | 40MHz ±10ppm | Required for bare SoC |

**Connectors on hub board:**

| Connector | Type | Connects to |
|-----------|------|------------|
| J1 | USB-C 16P | Power input + JTAG programming |
| J2–J5 | JST VH 2-pin | 20V power to each LED driver board |
| J6–J9 | JST XH 2-pin | DIM_PWM signal to each LED driver board |
| J10 | JST XH 4-pin | I2C to sensor board (SDA, SCL, 3.3V, GND) |
| J11 | JST XH 4-pin | UART to ESP32-CAM (TX, RX, 3.3V, GND) |
| J12 | JST XH 2-pin | Intake fan |
| J13 | JST XH 2-pin | Exhaust fan |
| J14 | 2-pin header | UART0 debug (TXD, RXD) |

**GPIO assignment:**

| GPIO | Function |
|------|---------|
| GPIO4 | SPI MOSI (TFT) |
| GPIO5 | SPI MISO (TFT) |
| GPIO6 | SPI CLK (TFT) |
| GPIO7 | TFT CS |
| GPIO8 | I2C SDA |
| GPIO9 | I2C SCL |
| GPIO10 | FUSB302 INT# |
| GPIO11 | LED DIM PWM |
| GPIO12 | Fan 1 PWM |
| GPIO13 | Fan 2 PWM |
| GPIO14 | TFT DC |
| GPIO17 | UART1 RX (camera) |
| GPIO18 | UART1 TX (camera) |
| GPIO19 | USB D- (JTAG) |
| GPIO20 | USB D+ (JTAG) |
| GPIO21 | TFT RST |
| GPIO38 | TFT backlight |
| GPIO39 | Touch CS |
| GPIO40 | Touch IRQ |
| GPIO41 | SD card CS |

---

### 2. LED Driver Board

> One of four identical driver boards. Each carries 3× TX6120 buck constant-current LED drivers, powering 3 strings of 5 LEDs each (15 LEDs, ~16W per board).

<p align="center">
  <img src="docs/images/pcb_driver_top.jpg" alt="Driver board top assembled" width="500"/>
  &nbsp;&nbsp;
  <img src="docs/images/pcb_driver_bottom.jpg" alt="Driver board bottom" width="500"/>
</p>

<p align="center">
  <img src="docs/driver_front.PNG" alt="Driver board KiCad 3D render" width="500"/>
  &nbsp;&nbsp;
  <img src="docs/driver_back.PNG" alt="Driver board KiCad 3D render back" width="500"/>
</p>

<p align="center">
  <img src="docs/images/pcb_driver_array.jpg" alt="All 4 driver boards side by side" width="700"/>
</p>

**Per-channel design (×3 per board):**

| Component | Value | Purpose |
|-----------|-------|---------|
| TX6120 | ESOP-8 | Buck CC LED driver, up to 100V, 1.5A |
| L1 | 330µH, Isat ≥500mA, shielded | Flyback inductor |
| D1 | SS14 (1A 40V SOD-123) | Freewheeling Schottky |
| R1 | 7.2kΩ 1% 0805 | VDD supply resistor |
| R2 | 0.75Ω 1% 0603 | Current sense — sets 340mA per string |
| C1 | 10µF 25V X7R 0805 | Input decoupling |
| C2 | 10nF 0402 | VDD bypass |
| C3 | 10nF 0402 | DIM pin filter |

**Current calculation:**

```
I_LED = Vcs / R2 = 0.255V / 0.75Ω = 340mA per string
Power per string = 5 LEDs × 3.2V × 0.340A = 5.44W
Power per board  = 3 strings × 5.44W = 16.3W
Total (4 boards) = 4 × 16.3W = 65.3W at 100% PWM
```

**Connectors:**

| Connector | Type | Signal |
|-----------|------|--------|
| J1 | JST VH 2-pin | 20V power in from hub |
| J2 | JST XH 2-pin | DIM_PWM + GND from hub |
| J3–J11 | JST XH 2-pin | LED+ and LED- per string (3 strings out) |

---

### 3. LED Panel Board

> One of four identical LED boards. Each carries 15× XL-3030WWC-1W-3V warm white LEDs in a 3×5 grid, mounted on FR4 with thermal vias under every LED pad and a B.Cu copper pour on the back side for heat spreading. An aluminum plate is bolted to the back of each board with thermal paste.

<p align="center">
  <img src="docs/images/pcb_led_top_off.jpg" alt="LED board not powered" width="500"/>
  &nbsp;&nbsp;
  <img src="docs/images/pcb_led_top_on.jpg" alt="LED board powered on" width="500"/>
</p>

<p align="center">
  <img src="docs/led_front.PNG" alt="LED board KiCad 3D render" width="500"/>
  &nbsp;&nbsp;
  <img src="docs/led_back.PNG" alt="LED board back showing copper pour and aluminum plate" width="500"/>
</p>

<p align="center">
  <img src="docs/images/pcb_led_panel_assembled.jpg" alt="All 4 LED boards assembled in 2x2 arrangement" width="700"/>
</p>

**LED specifications:**

| Parameter | Value |
|-----------|-------|
| LED | XL-3030WWC-1W-3V (XINGLIGHT) |
| LCSC | C2843893 |
| Package | SMD-3030-2P |
| Forward voltage | 3.2V typical |
| Rated current | 350mA |
| Operating current | 340mA (98% rated) |
| Color temperature | 2800–3200K warm white |
| Count per board | 15 (3 strings × 5 series) |

**Thermal design:**

```
LED thermal pad
      │
  9× vias (0.3mm drill) per LED
      │
B.Cu copper pour (full board flood)
      │
Thermal paste (Shin-Etsu X-23 or equivalent)
      │
3mm aluminum plate (bolted through 4 corner M3 holes)
```

**Board dimensions:** 85 × 55mm, FR4 1.6mm, HASL finish

**Connectors:**

| Connector | Type | Signal |
|-----------|------|--------|
| J1–J3 | JST XH 2-pin | LED+ and LED- per string (3 strings in from driver board) |

---

### 4. Sensor Board

> A minimal standalone board carrying only the AHT20 temperature and humidity sensor and its required passives. Connects to the hub via a 4-pin I2C cable. Designed to be mounted away from heat sources — ideally at mid-height on the cabinet wall for accurate ambient readings.

<p align="center">
  <img src="docs/sensor_front.PNG" alt="Sensor board top" width="400"/>
  &nbsp;&nbsp;
  <img src="docs/sensor_back.PNG" alt="Sensor board KiCad 3D render" width="400"/>
</p>

**Components:**

| Component | Value | Purpose |
|-----------|-------|---------|
| AHT20 | LCC-8 | Temperature (±0.3°C) and humidity (±2%RH) |
| C1 | 100nF 0402 | VDD decoupling |
| C2 | 10µF 0805 | Bulk decoupling |
| R1 | 4.7kΩ 0402 | I2C SDA pull-up |
| R2 | 4.7kΩ 0402 | I2C SCL pull-up |
| J1 | JST XH 4-pin | SDA, SCL, 3.3V, GND to hub |

**Board dimensions:** 25 × 20mm, FR4 1.6mm

> Pull-up resistors are on the sensor board rather than the hub board so the sensor board is self-contained and plug-and-play on any I2C bus.

---

## Web Dashboard

The dashboard is a single self-contained HTML file served directly from ESP32-S3 flash. No internet connection required. Access it at `http://growbox.local` from any device on the same WiFi network.

<p align="center">
  <img src="docs/images/dashboard_full.jpg" alt="Full dashboard screenshot" width="700"/>
</p>

<p align="center">
  <img src="docs/images/dashboard_mobile.jpg" alt="Dashboard on mobile" width="300"/>
  &nbsp;&nbsp;
  <img src="docs/images/dashboard_camera.jpg" alt="Dashboard with camera feed active" width="300"/>
  &nbsp;&nbsp;
  <img src="docs/images/dashboard_schedule.jpg" alt="Dashboard light schedule panel" width="300"/>
</p>

**Dashboard panels:**

| Panel | Description |
|-------|-------------|
| Camera feed | Live MJPEG stream from ESP32-CAM, tap to enable/disable |
| Temperature | Live °C reading, session min/max |
| Humidity | Live %RH reading, session min/max |
| LED brightness | Slider 0–100% with live watt estimation |
| Fan control | Independent intake and exhaust sliders |
| Light schedule | On/off time pickers, 24h visual timeline, enable toggle |
| System status | WiFi RSSI, uptime, PD status, free heap, grow day counter |
| Power summary | Estimated total wall draw |

---

## Camera Feed

The ESP32-CAM module mounts on the interior cabinet wall via a 3D printed bracket, angled downward to cover the full plant canopy. It connects to the hub board via a 4-wire UART cable.

<p align="center">
  <img src="docs/images/camera_mount.jpg" alt="ESP32-CAM mounted inside cabinet" width="500"/>
</p>

<p align="center">
  <img src="docs/images/camera_feed_plants.jpg" alt="Camera feed showing plants" width="600"/>
</p>

**Camera pipeline:**

```
OV2640 captures QVGA (320×240) JPEG
        │
        │ UART1 @ 921600 baud
        │ Framing: 0xFF 0xD8 [4-byte length] [JPEG] 0xFF 0xD9
        ▼
ESP32-S3 receives frame
        │
        │ HTTP multipart/x-mixed-replace
        ▼
Browser displays ~3fps MJPEG stream
```

On demand only — camera streams when a browser client has `/stream` open. ESP32-S3 sends `{"cmd":"stream","state":0}` when the client disconnects, stopping transmission and saving power.

---

## Wiring Overview

<p align="center">
  <img src="docs/images/wiring_diagram.jpg" alt="Full wiring diagram" width="800"/>
</p>

**Cable types used:**

| Connection | Connector | Wire | Current |
|-----------|-----------|------|---------|
| Hub → each LED driver board (power) | JST VH 2-pin | 20AWG | ~1A per board |
| Hub → each LED driver board (signal) | JST XH 2-pin | 26AWG UL2468 | <10mA |
| Driver board → LED strings | JST XH 2-pin | 26AWG UL2468 | 340mA |
| Hub → sensor board | JST XH 4-pin | 26AWG UL2468 | <5mA |
| Hub → fans | JST XH 2-pin | 24AWG | <500mA |
| Hub → ESP32-CAM | JST XH 4-pin | 26AWG | <300mA |

**Star topology for 20V power:**

```
Hub board
  ├──► LED Driver Board 1  (individual VH cable)
  ├──► LED Driver Board 2  (individual VH cable)
  ├──► LED Driver Board 3  (individual VH cable)
  └──► LED Driver Board 4  (individual VH cable)
```

Do not daisy-chain 20V through the driver boards. Each board gets its own direct cable from the hub to avoid cumulative voltage drop and overcurrent on a single connector.

---

## Features

- **USB-C PD negotiation** — full FUSB302 driver written from scratch in C. Requests 20V fixed PDO, handles Source_Capabilities, Accept, PS_RDY sequence. Retries every 30 seconds on failure. Detects cable disconnect and renegotiates automatically
- **LED brightness control** — 0–100% PWM via LEDC peripheral at 25kHz. Smooth 5-minute sunrise/sunset ramp on schedule transitions. Settings persisted to NVS
- **Light schedule** — configurable on/off time stored in NVS. SNTP time sync on WiFi connect. Timezone Europe/Brussels. Grow day counter from first boot timestamp
- **Fan control** — independent intake and exhaust speed 0–100%. Negative pressure maintained by running exhaust consistently higher than intake
- **Environment monitoring** — AHT20 polled every 10 seconds. Session min/max tracking for both temperature and humidity
- **Camera integration** — ESP32-CAM sends IP over UART on boot. Hub proxies MJPEG stream to browser on demand. Start/stop commands sent to camera over UART to save power when not viewing
- **Web dashboard** — fully self-contained single HTML file, dark theme, green accents, mobile responsive, no internet dependency
- **WiFi provisioning** — SoftAP captive portal on first boot for entering WiFi credentials. Saves to NVS, restarts, connects automatically on all subsequent boots
- **mDNS** — accessible at `growbox.local` after WiFi connect, no IP address needed

---

## API Endpoints

| Method | Endpoint | Description |
|--------|---------|-------------|
| GET | `/` | Web dashboard HTML |
| GET | `/api/status` | Full system status JSON |
| GET | `/api/sensors` | Temperature and humidity only |
| POST | `/api/led` | Set brightness `{"brightness": 0-100}` |
| POST | `/api/fans` | Set fan speeds `{"fan1": 0-100, "fan2": 0-100}` |
| GET | `/api/schedule` | Get light schedule |
| POST | `/api/schedule` | Set schedule `{"on":"06:00","off":"22:00","enabled":true}` |
| GET | `/api/camera` | Camera IP and stream URL |
| GET | `/stream` | MJPEG stream proxy from ESP32-CAM |
| POST | `/api/config/wifi` | Update WiFi credentials, triggers restart |

**Example `/api/status` response:**

```json
{
  "temp": 24.5,
  "humidity": 58.2,
  "temp_min": 22.1,
  "temp_max": 26.8,
  "humidity_min": 55.0,
  "humidity_max": 62.0,
  "led_brightness": 75,
  "led_watts": 48.75,
  "fan1_speed": 60,
  "fan2_speed": 75,
  "pd_negotiated": true,
  "pd_voltage_mv": 20000,
  "pd_current_ma": 3250,
  "wifi_rssi": -62,
  "uptime_seconds": 86423,
  "grow_day": 14,
  "lights_on": true,
  "minutes_until_transition": 342,
  "cam_ip": "192.168.1.105",
  "cam_online": true,
  "heap_free": 187432,
  "firmware_version": "1.0.0"
}
```

---

## Project Structure

```
growbox-firmware/
├── docs/
│   └── images/                     # All images referenced in this README
├── main/
│   ├── main.c                      # app_main, init sequence, task spawning
│   ├── fusb302.c / fusb302.h       # FUSB302 I2C register driver
│   ├── fusb302_pd.c / fusb302_pd.h # USB PD protocol state machine
│   ├── aht20.c / aht20.h           # AHT20 temperature/humidity driver
│   ├── led_control.c / led_control.h # LEDC LED and fan PWM control
│   ├── schedule.c / schedule.h     # Light schedule logic and SNTP
│   ├── wifi_manager.c / wifi_manager.h # WiFi, mDNS, captive portal
│   ├── http_server.c / http_server.h   # All HTTP endpoint handlers
│   ├── uart_cam.c / uart_cam.h     # ESP32-CAM UART protocol
│   ├── nvs_config.c / nvs_config.h # NVS read/write helpers
│   ├── state.c / state.h           # Global state struct and mutex
│   ├── dashboard.h                 # Embedded dashboard HTML string
│   └── CMakeLists.txt
├── partitions.csv                  # Custom partition table
├── sdkconfig.defaults              # Default SDK configuration
├── CMakeLists.txt
└── README.md
```

---

## FreeRTOS Task Structure

| Task | Stack (bytes) | Priority | Core |
|---|---|---|---|
| pd_task | 4096 | 5 | 0 |
| wifi_task | 4096 | 4 | 0 |
| uart_cam_task | 4096 | 4 | 1 |
| sensor_task | 2048 | 3 | 0 |
| schedule_task | 2048 | 2 | 1 |

HTTP server runs in its own internal task via `esp_http_server`.

Inter-task communication:
- `pd_event_queue` — depth 8, FUSB302 interrupt events from GPIO ISR to pd_task
- `sensor_data_queue` — depth 2, latest AHT20 readings

All shared state lives in a single global struct protected by one FreeRTOS mutex. HTTP handlers read from this struct under the mutex. No blocking calls in HTTP handler context.

---

## NVS Configuration

Namespace: `growbox`

| Key | Type | Default | Description |
|-----|---|---|---|
| `wifi_ssid` | string | — | WiFi network name |
| `wifi_pass` | string | — | WiFi password |
| `led_brightness` | uint8 | 70 | LED brightness percent |
| `fan1_speed` | uint8 | 50 | Intake fan speed percent |
| `fan2_speed` | uint8 | 60 | Exhaust fan speed percent |
| `sched_on` | uint16 | 360 | Light on time (minutes since midnight, 360 = 06:00) |
| `sched_off` | uint16 | 1320 | Light off time (minutes since midnight, 1320 = 22:00) |
| `sched_enabled` | uint8 | 1 | Schedule active flag |
| `first_boot_ts` | uint32 | 0 | Unix timestamp of first boot for grow day counter |
| `firmware_ver` | string | "1.0.0" | Firmware version string |

---

## Building and Flashing

### Prerequisites

- ESP-IDF v5.x installed and sourced (`source $IDF_PATH/export.sh`)
- USB-C cable connected to hub board (USB Serial/JTAG on GPIO19/GPIO20, no separate programmer needed)

### Clone and build

```bash
git clone https://github.com/yourusername/growbox-firmware
cd growbox-firmware
idf.py set-target esp32s3
idf.py build
```

### Flash

```bash
idf.py -p /dev/ttyACM0 flash monitor
```

On first boot with no WiFi credentials in NVS, the device starts a setup access point:

```
SSID:     GrowBox-Setup
Password: growbox123
URL:      http://192.168.4.1
```

Connect to this network, open the URL, enter your WiFi credentials. Device restarts and connects. Access the dashboard at:

```
http://growbox.local
```

### JTAG debug

USB Serial/JTAG is available natively on GPIO19/GPIO20 via the USB-C connector. No external probe needed. Use OpenOCD with the ESP32-S3 built-in target:

```bash
openocd -f board/esp32s3-builtin.cfg
>>>>>>> 2fca156416b63ba39733e7f331657d6a7e1e1554
```

---

<<<<<<< HEAD
## First boot / WiFi setup

With no WiFi credentials stored, the device starts a SoftAP
**`GrowBox-Setup`** (password `growbox123`). Connect to it and browse to
`192.168.4.1` to enter your real WiFi credentials; the device saves them
to NVS and restarts. On subsequent boots it connects directly and the
dashboard becomes reachable at `http://growbox.local/` (mDNS) or its
DHCP-assigned IP.

## Passcode

The dashboard's lock screen passcode is `4712` by default, stored in NVS
key `auth_code` under the `growbox` namespace. There's currently no HTTP
endpoint to change it — only to log in with it.

## Known gaps / things to bench-test

- **USB-PD negotiation** (`fusb302.c`, `fusb302_pd.c`) is a from-scratch
  driver against the FUSB302B register map and USB PD 2.0 message
  format. It hasn't been run against real silicon or a real charger.
  Budget time with a logic analyzer on the CC line — PD signaling is
  unforgiving of a single wrong register bit, and reference drivers
  vary in the exact FIFO token sequence they use.
- **No SD logging / no fan auto-mode**: both removed per request. The
  dashboard's fan sliders are pure manual control, and there's no
  historical data logging anywhere (`/api/log` doesn't exist).
- **Auth** (`auth.c`, `POST /api/auth`) isn't in the original firmware
  spec — it's there because the dashboard already implements a passcode
  + bearer-token flow and needed something to talk to. Fine for a
  LAN-only home device; not hardened against an attacker who already
  has network access to it.
- **Dev container USB access** uses `--privileged` + a full `/dev` bind
  mount (see `.devcontainer/devcontainer.json`) so the board's serial
  port is visible without hardcoding its exact path. That's broad device
  access — a reasonable tradeoff for a personal local dev container, but
  worth knowing it's not a sandboxed container in the usual sense.
=======
## ESP32-CAM Setup

The ESP32-CAM runs independently on the same WiFi network. Flash it with ESP32-CAM-WebServer firmware modified to:

1. Connect to the same WiFi network as the hub
2. Send its IP address over UART at 921600 baud on boot: `{"cam_ip":"192.168.1.x"}\n`
3. Accept stream start/stop commands over UART: `{"cmd":"stream","state":1}`
4. Output QVGA (320×240) JPEG frames framed as: `0xFF 0xD8` [4-byte big-endian length] [JPEG data] `0xFF 0xD9`

The hub stores the camera IP in RAM on receipt and uses it to construct the stream proxy URL. Assign the ESP32-CAM a static IP in your router DHCP settings for reliability.

**Physical mounting:**

Mount the ESP32-CAM on the interior cabinet wall at approximately 2/3 height, angled 30–45° downward toward the canopy center. A simple 3D printed bracket with a snap-fit camera slot works well. Run the 4-wire UART cable along the cabinet wall to the hub board.

---

## Grow Schedule Recommendations

| Crop | Light on | Light off | Hours | Brightness |
|---|---|---|---|---|
| Seedlings (all) | 06:00 | 22:00 | 16h | 40% |
| Vegetative cannabis | 06:00 | 00:00 | 18h | 70% |
| Autoflower full cycle | 06:00 | 00:00 | 18h | 75% |
| Photoperiod flowering | 08:00 | 20:00 | 12h | 85% |
| Peppers / chili | 06:00 | 22:00 | 16h | 65% |
| Herbs / lettuce | 06:00 | 22:00 | 16h | 55% |
| Microgreens | 06:00 | 22:00 | 16h | 45% |

**Estimated power at different brightness levels:**

| Brightness | LED power | Total estimated wall draw |
|---|---|---|
| 40% | 26W | ~30W |
| 50% | 32.5W | ~37W |
| 65% | 42.3W | ~47W |
| 75% | 48.8W | ~54W |
| 85% | 55.3W | ~61W |
| 100% | 65W | ~72W |

---

## Bill of Materials

### Hub Board

| Component | Part | LCSC | Qty | Unit | Total |
|---|---|---|-----|---|---|
| ESP32-S3 SoC | ESP32-S3 QFN-56 | — | 1 | ~€2.50 | €2.50 |
| NOR Flash | GD25WQ64ESIGR | — | 1 | ~€0.80 | €0.80 |
| PD controller | FUSB302UCX | C481901 | 1 | €0.46 | €0.46 |
| 3.3V buck | SY8120B | — | 1 | €0.15 | €0.15 |
| Crystal 40MHz | ±10ppm | — | 1 | €0.20 | €0.20 |
| USB-C receptacle | 16P SMD | C165948 | 1 | €0.18 | €0.18 |
| AHT20 (on sensor board) | AHT20 | C2757724 | 1 | €0.58 | €0.58 |
| Passives + connectors | — | — | — | — | ~€2.00 |
| **Hub total** | | | | | **~€6.87** |

### LED Driver Boards (×4)

| Component | Part | LCSC | Qty/board | Unit | Per board | ×4 |
|---|---|---|---|---|---|-----|
| TX6120 driver | TX6120 ESOP-8 | C329272 | 3 | €0.26 | €0.78 | €3.12 |
| Inductor 330µH | Isat ≥500mA shielded | — | 3 | €0.25 | €0.75 | €3.00 |
| Schottky SS14 | 1A 40V SOD-123 | C2480 | 3 | €0.03 | €0.09 | €0.36 |
| R_sense 0.75Ω | 1% 0603 | — | 3 | €0.02 | €0.06 | €0.24 |
| R_VDD 7.2kΩ | 1% 0805 | — | 3 | €0.01 | €0.03 | €0.12 |
| C_in 10µF 25V | X7R 0805 | — | 3 | €0.03 | €0.09 | €0.36 |
| Passives + connectors | — | — | — | — | €0.30 | €1.20 |
| **Per board** | | | | | **€2.10** | **€8.40** |

### LED Panel Boards (×4)

| Component | Part | LCSC | Qty/board | Unit | Per board | ×4 |
|---|---|---|---|---|---|-----|
| Warm white LED | XL-3030WWC-1W-3V | C2843893 | 15 | €0.034 | €0.51 | €2.04 |
| Connectors + passives | — | — | — | — | €0.20 | €0.80 |
| **Per board** | | | | | **€0.71** | **€2.84** |

### Other

| Item | Cost |
|---|---|
| ESP32-CAM module | ~€3.00 |
| 100W GaN USB-C charger | ~€20.00 |
| 120mm PC fans ×2 | ~€6.00 |
| JST cables and connectors | ~€3.00 |
| Aquarium activated carbon | ~€4.00 |
| MDF + hardware for cabinet | ~€25.00 |
| Mylar reflective film | ~€5.00 |
| Aluminum backing plates ×4 | ~€4.00 |
| EPDM door seal + latches | ~€5.00 |

**Total estimated build cost: ~€95–110**

---

## License

MIT License — see [LICENSE](LICENSE) file.

---

<p align="center">
  Made by Arik · IoT & Electronics Engineering Student · Belgium
</p>

<p align="center">
  Plants growing inside the cabinet
</p>
>>>>>>> 2fca156416b63ba39733e7f331657d6a7e1e1554

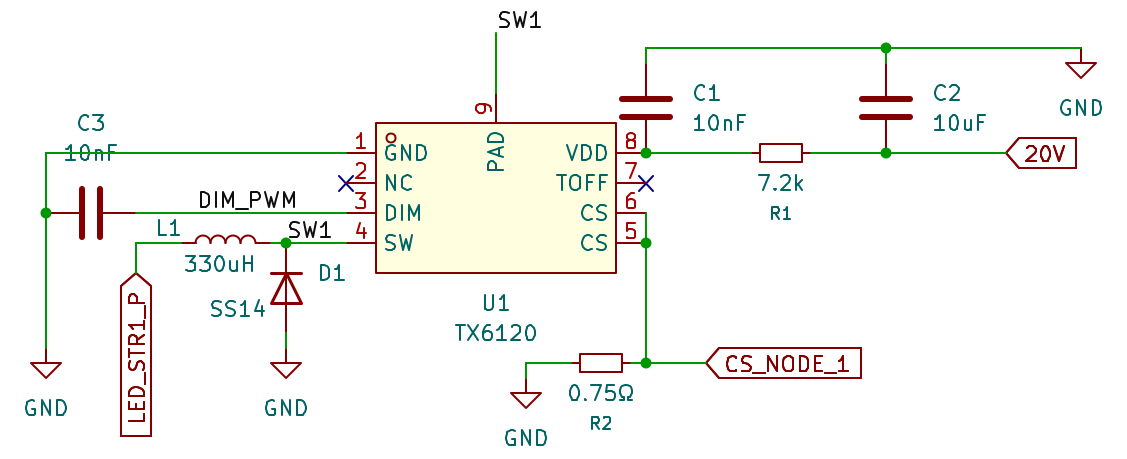
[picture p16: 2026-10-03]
docs/images/driver schematic.png

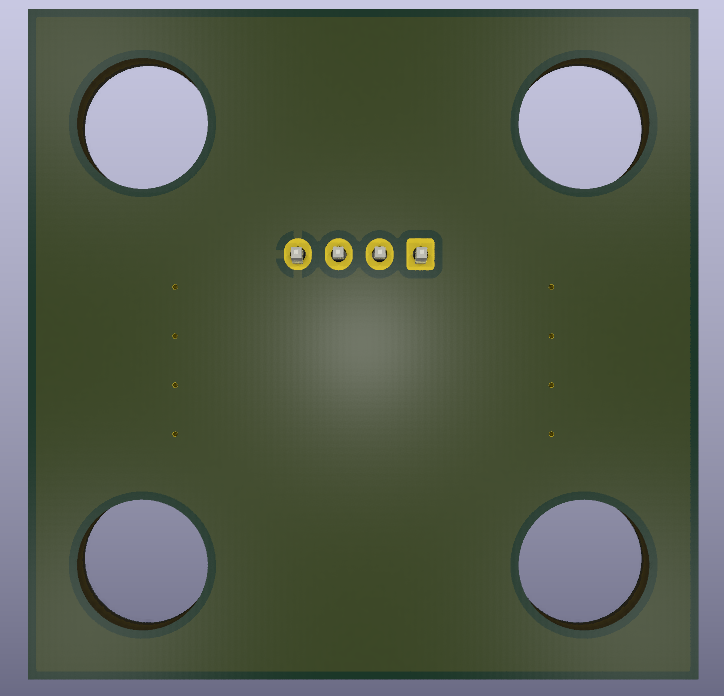
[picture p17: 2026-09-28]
docs/images/sensor_back.PNG

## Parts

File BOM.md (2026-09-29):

# Bill of Materials

Part of the [GrowBox](README.md) build. Component pricing is rough LCSC/JLCPCB-tier
estimates, not real quotes — swap in your own once you've ordered. PCB
fabrication and 3D-printed parts were missing from earlier versions of this
list; they're now included since they're a real chunk of the total cost.

---

### Hub Board (×1)

| Component | Part | LCSC | Qty | Unit | Total |
|---|---|---|-----|---|---|
| ESP32-S3 SoC | ESP32-S3 QFN-56 | — | 1 | ~€2.50 | €2.50 |
| NOR Flash | GD25WQ64ESIGR | — | 1 | ~€0.80 | €0.80 |
| PD controller | FUSB302UCX | C481901 | 1 | €0.46 | €0.46 |
| 3.3V regulator | AP63203 | — | 1 | €0.15 | €0.15 |
| Crystal 40MHz | ±10ppm | — | 1 | €0.20 | €0.20 |
| USB-C receptacle | 16-pin SMD | C165948 | 1 | €0.18 | €0.18 |
| Passives + connectors | — | — | — | — | ~€2.00 |
| **Subtotal** | | | | | **~€6.30** |

### LED Driver Boards (×4, 4 channels each)

| Component | Part | LCSC | Qty/board | Unit | Per board | ×4 |
|---|---|---|---|---|---|-----|
| TX6120 driver | TX6120 ESOP-8 | C329272 | 4 | €0.26 | €1.04 | €4.16 |
| Inductor 330µH | Isat ≥500mA shielded | — | 4 | €0.25 | €1.00 | €4.00 |
| Schottky SS14 | 1A 40V SOD-123 | C2480 | 4 | €0.03 | €0.12 | €0.48 |
| R_sense 0.75Ω | 1% 0603 | — | 4 | €0.02 | €0.08 | €0.32 |
| R_VDD 7.2kΩ | 1% 0805 | — | 4 | €0.01 | €0.04 | €0.16 |
| C_in 10µF 25V | X7R 0805 | — | 4 | €0.03 | €0.12 | €0.48 |
| Passives + connectors | — | — | — | — | €0.30 | €1.20 |
| **Subtotal** | | | | | **€2.70/board** | **€10.80** |

### LED Panel Boards (×4, 20 LEDs each)

| Component | Part | LCSC | Qty/board | Unit | Per board | ×4 |
|---|---|---|---|---|---|-----|
| Warm white LED | XL-3030WWC-1W-3V | C2843893 | 20 | €0.034 | €0.68 | €2.72 |
| Connectors + passives | — | — | — | — | €0.20 | €0.80 |
| **Subtotal** | | | | | **€0.88/board** | **€3.52** |

### Sensor Board (×1)

| Component | Part | LCSC | Qty | Unit | Total |
|---|---|---|---|-----|---|---|
| AHT20 | LCC-8 | C2757724 | 1 | €0.58 | €0.58 |
| C1 100nF | 0402 | — | 1 | €0.01 | €0.01 |
| C2 10µF | 0805 | — | 1 | €0.03 | €0.03 |
| R1, R2 4.7kΩ pull-ups | 0402 | — | 2 | €0.01 | €0.02 |
| Connector | JST XH 4-pin | — | 1 | €0.05 | €0.05 |
| **Subtotal** | | | | | **~€0.70** |

### PCB Fabrication (JLCPCB, 5-board minimum batch per design)

| Board | Spec | Est. cost |
|---|---|---|
| Hub board | 2-layer FR4, ~50×70mm | ~€8 |
| LED driver board | 2-layer FR4 | ~€8 |
| LED panel board | Single-layer, aluminum-bottom, 85×55mm | ~€12 |
| Sensor board | 2-layer FR4, 25×20mm | ~€5 |
| **Subtotal** (4 batches — extras usable as spares) | | **~€33** |

### 3D Printed Parts

| Part | Material | Est. cost |
|---|---|---|
| Camera mount bracket | PLA/PETG, ~15g | ~€1 |
| Carbon filter housing | PLA/PETG, ~40g | ~€2 |
| **Subtotal** | | **~€3** |

### Other

| Item | Cost |
|---|---|
| ESP32-CAM module | ~€3.00 |
| 100W GaN USB-C charger | ~€20.00 |
| 120mm PC fans ×2 | ~€6.00 |
| JST cables and connectors | ~€3.00 |
| Aquarium activated carbon | ~€4.00 |
| MDF + hardware for cabinet | ~€25.00 |
| Mylar reflective film | ~€5.00 |
| EPDM door seal + latches | ~€5.00 |
| **Subtotal** | **~€71.00** |

---

**Total estimated build cost: ~€125–135**

(Roughly €30 higher than earlier estimates — those omitted PCB fabrication entirely, which isn't optional.)

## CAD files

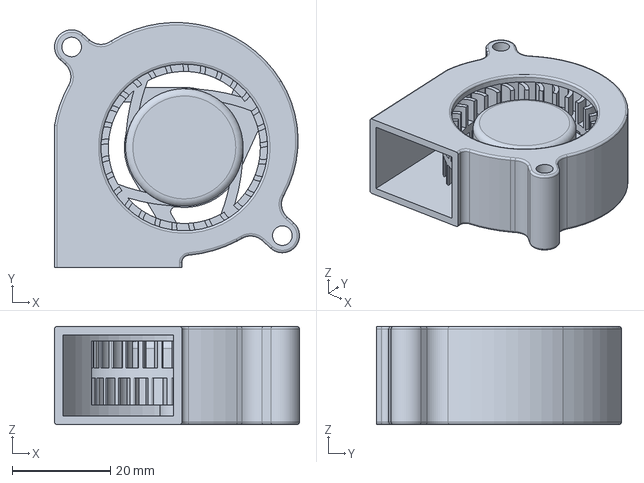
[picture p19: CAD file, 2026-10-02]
docs/CAD/50x20blower.step
50.0 x 50.0 x 20.0 mm

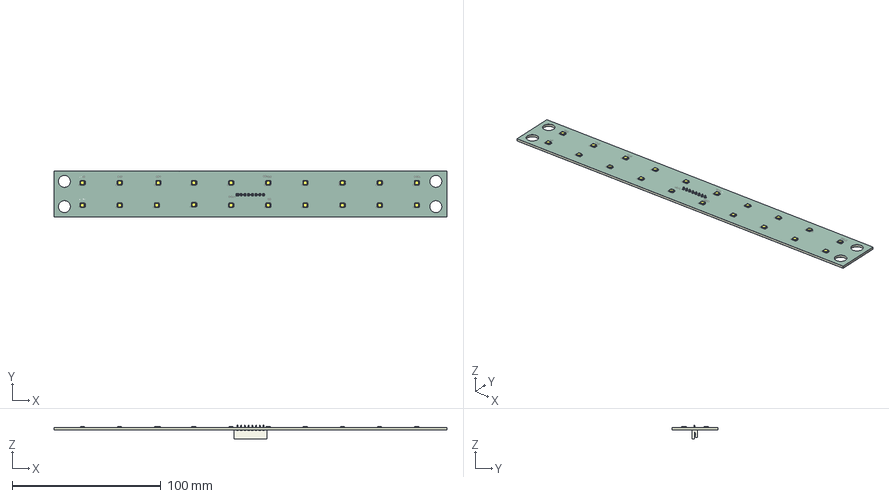
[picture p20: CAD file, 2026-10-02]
docs/CAD/led_board/led_board.step
264.5 x 31.0 x 9.20 mm
LED-SMD_L3.0-W3.0_WHITE x 20
JST_B8B_EH_A
aux_copper
aux_pad
aux_silkscreen x 2
aux_soldermask x 2
aux_PCB

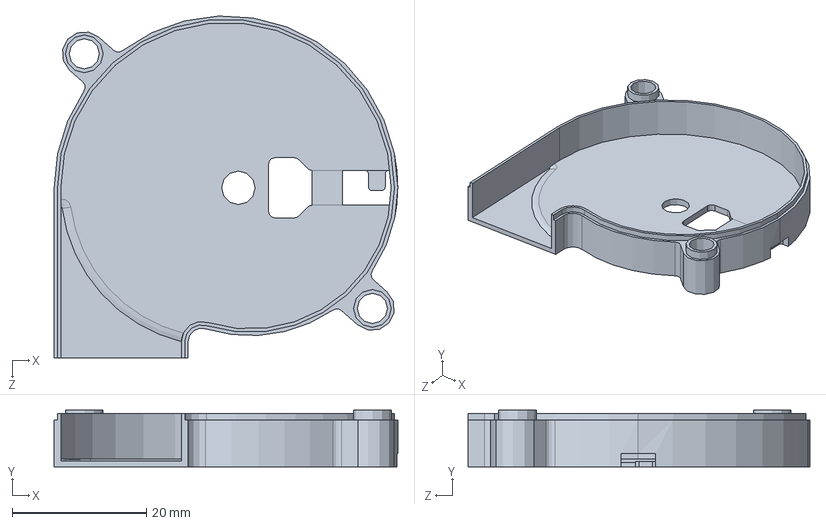
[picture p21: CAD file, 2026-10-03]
docs/CAD/Radial Cooling Fan 50mm DC12V/bottom.SLDPRT
51.3 x 8.50 x 51.0 mm

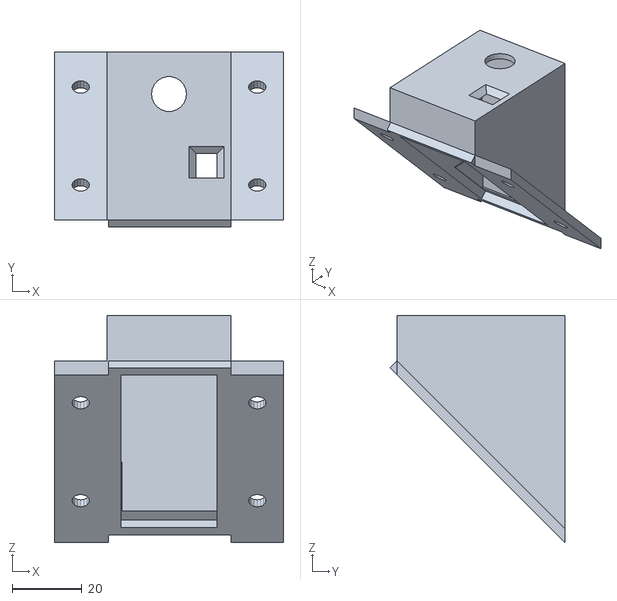
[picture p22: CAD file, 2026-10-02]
esp32cam/CAD FILES/mount.stl
65.5 x 50.0 x 65.0

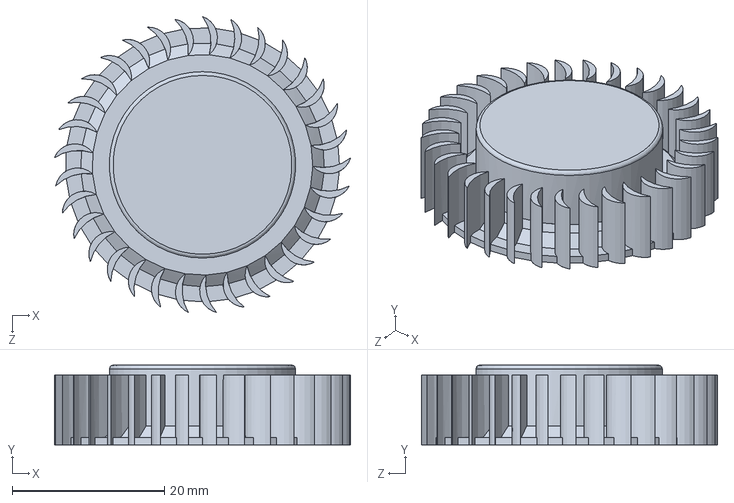
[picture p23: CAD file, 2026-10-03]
docs/CAD/Radial Cooling Fan 50mm DC12V/turbine.SLDPRT
39.0 x 10.5 x 38.9 mm

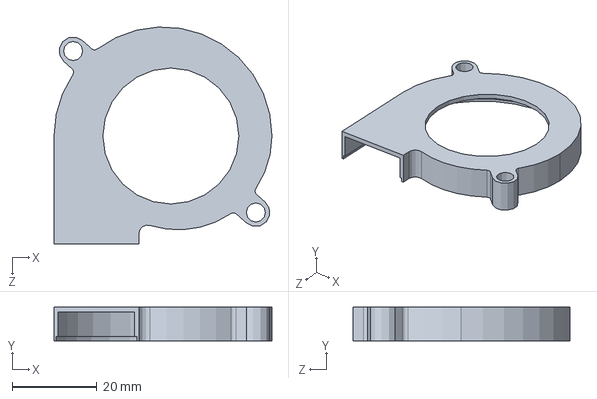
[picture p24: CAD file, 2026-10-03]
docs/CAD/Radial Cooling Fan 50mm DC12V/top.SLDPRT
51.3 x 8.00 x 51.0 mm

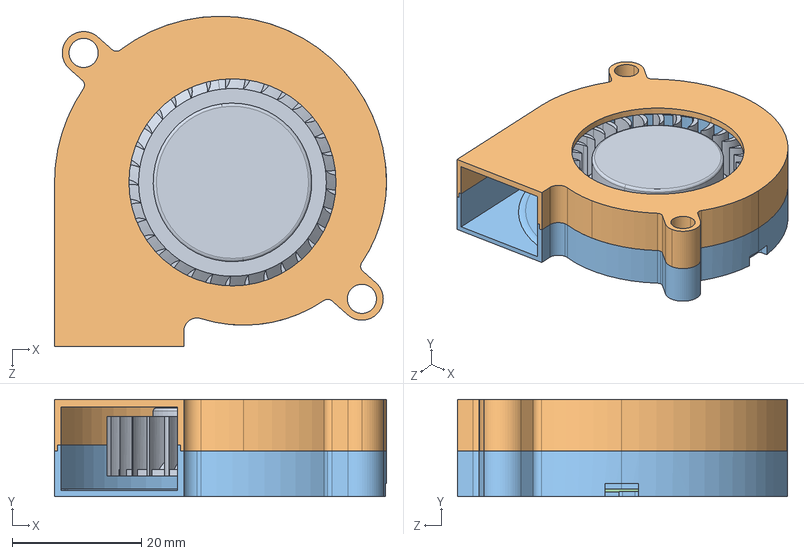
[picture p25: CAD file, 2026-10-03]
docs/CAD/Radial Cooling Fan 50mm DC12V/Radial-Cooling-Fan-5015-DC12V.STEP
51.3 x 15.0 x 51.1 mm
turbine
top
bottom

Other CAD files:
docs/CAD/50x20blower/50x20blower.ipt
docs/CAD/OldVersions/box.0003.ipt
docs/CAD/OldVersions/fan_duct.0001.ipt
docs/CAD/OldVersions/growbox.0004.iam
docs/CAD/Radial Cooling Fan 50mm DC12V/Radial-Cooling-Fan-5015-DC12V.SLDASM
docs/CAD/Radial Cooling Fan 50mm DC12V/Radial-Cooling-Fan-5015-DC12V/Radial-Cooling-Fan-5015-DC12V.ipt
docs/CAD/box.idw
docs/CAD/box.ipt
docs/CAD/fan_duct.ipt
docs/CAD/growbox.iam
docs/CAD/heatsink.ipt
docs/CAD/led_board/led_board.ipt
docs/OldVersions/box.0001.ipt
esp32cam/CAD FILES/ESP32CAM MOUNT.ipt

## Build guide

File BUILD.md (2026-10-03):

# Build & Technical Reference

Part of the [GrowBox](README.md) build. This is the engineering reference —
GPIO pinout, wiring, connectors, NVS config, task structure, and build/flash
steps. For photos and an overview of the build, see the [README](README.md).
Parts list and cost: [BOM.md](BOM.md).

---

## System Architecture

```
                        USB-C PD Charger (100W GaN)
                                  │
                                  │ 20V @ up to 5A
                                  ▼
                    ┌──────────────────────────────┐
                    │        MAIN HUB BOARD        │
                    │                              │
                    │  FUSB302 ──► 20V rail        │
                    │  ESP32-S3                    │
                    │  AP63203 Buck ──► 3.3V logic │
                    │  AHT20 sensor board (ext.)   │
                    │  ESP32-CAM (ext. via UART)   │
                    └──────────┬───────────────────┘
                               │
               ┌───────────────┼───────────────┐
               │               │               │
               ▼               ▼               ▼
        LED Board 1      LED Board 2     LED Board 3+4
       (4× TX6120)      (4× TX6120)     (4× TX6120 each)
       20 LEDs           20 LEDs         20 LEDs each
       ~21.8W            ~21.8W          ~21.8W each
```

All four LED driver boards receive:
- **20V power** via individual JST VH 2-pin cables (star topology from hub)
- **DIM_PWM signal** via 2-pin signal cable (daisy-chainable, milliamp level)

---

## PCB Details

All four boards designed in KiCad, manufactured at JLCPCB.

### 1. Main Hub Board

**Key components:**

| Component | Part | Description |
|---|---|---|
| MCU | ESP32-S3 QFN-56 | Dual-core 240MHz, WiFi+BLE, USB JTAG |
| Flash | GD25WQ64ESIGR | 8MB NOR SPI flash, WSON-8 |
| PD controller | FUSB302UCX | USB-C PD sink, I2C controlled |
| 3.3V regulator | AP63203 | 32V input, 2A buck |
| USB-C receptacle | 16-pin SMD | Power + CC1/CC2 for FUSB302 + D+/D- for JTAG |
| Crystal | 40MHz ±10ppm | Required for bare SoC |

**Connectors:**

| Connector | Type | Connects to |
|---|---|---|
| J1 | USB-C 16P | Power input + JTAG programming |
| J2–J5 | JST VH 2-pin | 20V power to each LED driver board |
| J6–J9 | JST XH 2-pin | DIM_PWM signal to each LED driver board |
| J10 | JST XH 4-pin | I2C to sensor board (SDA, SCL, 3.3V, GND) |
| J11 | JST XH 4-pin | UART to ESP32-CAM (TX, RX, 3.3V, GND) |
| J12 | JST XH 2-pin | Intake fan |
| J13 | JST XH 2-pin | Exhaust fan |
| J14 | 2-pin header | UART0 debug (TXD, RXD) |

**GPIO assignment:**

| GPIO | Function |
|---|---|
| GPIO4 | SPI MOSI (SD card) |
| GPIO5 | SPI MISO (SD card) |
| GPIO6 | SPI CLK (SD card) |
| GPIO8 | I2C SDA |
| GPIO9 | I2C SCL |
| GPIO10 | FUSB302 INT# |
| GPIO11 | LED DIM PWM |
| GPIO12 | Fan 1 PWM |
| GPIO13 | Fan 2 PWM |
| GPIO17 | UART1 RX (camera) |
| GPIO18 | UART1 TX (camera) |
| GPIO19 | USB D- (JTAG) |
| GPIO20 | USB D+ (JTAG) |
| GPIO41 | SD card CS |

### 2. LED Driver Board

One of four identical boards, 4× TX6120 buck constant-current drivers each.

**Per-channel design (×4 per board):**

| Component | Value | Purpose |
|---|---|---|
| TX6120 | ESOP-8 | Buck CC LED driver, up to 100V, 1.5A |
| L1 | 330µH, Isat ≥500mA, shielded | Flyback inductor |
| D1 | SS14 (1A 40V SOD-123) | Freewheeling Schottky |
| R1 | 7.2kΩ 1% 0805 | VDD supply resistor |
| R2 | 0.75Ω 1% 0603 | Current sense — sets 340mA per string |
| C1 | 10µF 25V X7R 0805 | Input decoupling |
| C2 | 10nF 0402 | VDD bypass |
| C3 | 10nF 0402 | DIM pin filter |

**Current calculation:**

```
I_LED = Vcs / R2 = 0.255V / 0.75Ω = 340mA per string
Power per string = 5 LEDs × 3.2V × 0.340A = 5.44W
Power per board  = 4 strings × 5.44W = 21.76W
Total (4 boards) = 4 × 21.76W = 87W at 100% PWM
```

**Connectors:**

| Connector | Type | Signal |
|---|---|---|
| J1 | JST VH 2-pin | 20V power in from hub |
| J2 | JST XH 2-pin | DIM_PWM + GND from hub |
| J3–J6 | JST XH 2-pin | LED+ and LED- per string (4 strings out) |

### 3. LED Panel Board

One of four identical boards, 20× XL-3030WWC-1W-3V warm white LEDs each (80
total). Single-layer FR4 board with an aluminum bottom layer — not a
separate bolted-on plate.

**LED specifications:**

| Parameter | Value |
|---|---|
| LED | XL-3030WWC-1W-3V (XINGLIGHT) |
| LCSC | C2843893 |
| Package | SMD-3030-2P |
| Forward voltage | 3.2V typical |
| Rated current | 350mA |
| Operating current | 340mA (98% rated) |
| Color temperature | 2800–3200K warm white |
| Count per board | 20 (4 strings × 5 series) |

**Thermal path:** LED thermal pad → 9× vias (0.3mm drill) per LED → B.Cu
copper pour (full board flood) → thermal paste (Shin-Etsu X-23 or
equivalent) → aluminum bottom layer, integral to the board.

**Board dimensions:** 85 × 55mm, FR4 1.6mm, HASL finish

**Connectors:**

| Connector | Type | Signal |
|---|---|---|
| J1–J4 | JST XH 2-pin | LED+ and LED- per string (4 strings in from driver board) |

### 4. Sensor Board

Minimal standalone board, AHT20 only. Connects via 4-pin I2C cable; mount
away from heat sources for accurate ambient readings.

**Components:**

| Component | Value | Purpose |
|---|---|---|
| AHT20 | LCC-8 | Temperature (±0.3°C) and humidity (±2%RH) |
| C1 | 100nF 0402 | VDD decoupling |
| C2 | 10µF 0805 | Bulk decoupling |
| R1 | 4.7kΩ 0402 | I2C SDA pull-up |
| R2 | 4.7kΩ 0402 | I2C SCL pull-up |
| J1 | JST XH 4-pin | SDA, SCL, 3.3V, GND to hub |

**Board dimensions:** 25 × 20mm, FR4 1.6mm

Pull-ups live on the sensor board rather than the hub so it's self-contained
and plug-and-play on any I2C bus.

---

## Wiring

**Cable types:**

| Connection | Connector | Wire | Current |
|---|---|---|---|
| Hub → each LED driver board (power) | JST VH 2-pin | 20AWG | ~1A per board |
| Hub → each LED driver board (signal) | JST XH 2-pin | 26AWG UL2468 | <10mA |
| Driver board → LED strings | JST XH 2-pin | 26AWG UL2468 | 340mA |
| Hub → sensor board | JST XH 4-pin | 26AWG UL2468 | <5mA |
| Hub → fans | JST XH 2-pin | 24AWG | <500mA |
| Hub → ESP32-CAM | JST XH 4-pin | 26AWG | <300mA |

**Star topology for 20V power** — each driver board gets its own direct
cable from the hub; don't daisy-chain 20V through the boards, to avoid
cumulative voltage drop and overcurrent on a single connector:

```
Hub board
  ├──► LED Driver Board 1  (individual VH cable)
  ├──► LED Driver Board 2  (individual VH cable)
  ├──► LED Driver Board 3  (individual VH cable)
  └──► LED Driver Board 4  (individual VH cable)
```

---

## Camera pipeline

```
OV2640 captures QVGA (320×240) JPEG
        │
        │ UART1 @ 921600 baud
        │ Framing: 0xFF 0xD8 [4-byte length] [JPEG] 0xFF 0xD9
        ▼
ESP32-S3 receives frame
        │
        │ HTTP multipart/x-mixed-replace
        ▼
Browser displays ~3fps MJPEG stream
```

On demand only — camera streams while a browser client has `/stream` open.
ESP32-S3 sends `{"cmd":"stream","state":0}` on client disconnect, stopping
transmission and saving power.

### ESP32-CAM setup

Has no network connectivity of its own — see [esp32cam/README.md](esp32cam/README.md)
for the actual firmware (bare ESP-IDF, not ESP32-CAM-WebServer). Everything
goes over the dedicated UART link to the hub:

1. Announces it's up over UART at 921600 baud on boot: `{"ready":true}\n`
2. Accepts stream start/stop commands over UART: `{"cmd":"stream","state":1}`
3. Outputs QVGA (320×240) JPEG frames framed as: `0xFF 0xD8` [4-byte big-endian length] [JPEG data] `0xFF 0xD9`

The hub tracks camera liveness in RAM from the `ready` message and from
frames actually arriving — there's no IP address anywhere in this picture,
since the video never leaves the UART link.

**Mounting:** interior cabinet wall, ~2/3 height, angled 30–45° downward
toward canopy center. 3D printed bracket with a snap-fit slot; run the
4-wire UART cable along the wall to the hub board.

---

## Project structure

```
microgrowery/
├── README.md                    # showcase
├── BUILD.md                     # this file
├── BOM.md                       # parts list and cost
├── dashboard.html               # browser dashboard (source of truth)
├── Dockerfile                   # ESP-IDF build image
├── docker-compose.yml           # build/flash/monitor services
├── .devcontainer/                # VS Code dev container config
├── scripts/                     # host-side build/flash/monitor helpers
├── docs/images/                 # all images referenced in the README
└── firmware/                    # ESP-IDF project
    ├── CMakeLists.txt
    ├── partitions.csv
    ├── sdkconfig.defaults
    └── main/
        ├── main.c                        # app_main, init sequence, task spawning
        ├── fusb302.c / fusb302.h         # FUSB302 I2C register driver
        ├── fusb302_pd.c / fusb302_pd.h   # USB PD protocol state machine
        ├── aht20.c / aht20.h             # AHT20 temperature/humidity driver
        ├── led_control.c / led_control.h # LEDC LED and fan PWM control
        ├── schedule.c / schedule.h       # Light schedule logic and SNTP
        ├── wifi_manager.c / wifi_manager.h # WiFi, mDNS, captive portal
        ├── auth.c / auth.h               # Dashboard passcode + bearer tokens
        ├── http_server.c / http_server.h # All HTTP endpoint handlers
        ├── uart_cam.c / uart_cam.h       # ESP32-CAM UART protocol
        ├── nvs_config.c / nvs_config.h   # NVS read/write helpers
        ├── state.c / state.h             # Global state struct and mutex
        ├── dashboard.html                # embedded copy of the root dashboard.html
        └── CMakeLists.txt
```

---

## FreeRTOS task structure

| Task | Stack (bytes) | Priority | Core |
|---|---|---|---|
| pd_task | 4096 | 5 | 0 |
| wifi_task | 4096 | 4 | 0 |
| uart_cam_task | 4096 | 4 | 1 |
| sensor_task | 2048 | 3 | 0 |

HTTP server runs in its own internal task via `esp_http_server`. The light
schedule isn't a dedicated task — it's a periodic `esp_timer` callback,
checked every 60 seconds.

Inter-task communication: `pd_event_queue` (depth 8) carries FUSB302
interrupt events from the GPIO ISR to `pd_task`. Everything else — sensor
readings, LED/fan/schedule/PD/WiFi status — lives in one global struct
protected by a single FreeRTOS mutex; `sensor_task`, `pd_task` and the HTTP
handlers all read/write it under that lock rather than passing data through
queues.

---

## NVS configuration

Namespace: `growbox`

| Key | Type | Default | Description |
|-----|---|---|---|
| `wifi_ssid` | string | — | WiFi network name |
| `wifi_pass` | string | — | WiFi password |
| `led_brightness` | uint8 | 70 | LED brightness percent |
| `fan1_speed` | uint8 | 50 | Intake fan speed percent |
| `fan2_speed` | uint8 | 60 | Exhaust fan speed percent |
| `sched_on` | uint16 | 360 | Light on time (minutes since midnight, 360 = 06:00) |
| `sched_off` | uint16 | 1320 | Light off time (minutes since midnight, 1320 = 22:00) |
| `sched_enabled` | uint8 | 1 | Schedule active flag |
| `first_boot_ts` | uint32 | 0 | Unix timestamp of first boot, for grow day counter |
| `auth_code` | string | "4712" | Dashboard lock-screen passcode |

---

## Building and flashing

Firmware lives in `firmware/`, built via Docker — no local ESP-IDF install
needed. Open the repo root in VS Code and accept "Reopen in Container" to
build from the integrated terminal (`idf.py build`), or run manually from
the repo root:

```bash
docker compose run --rm build
docker compose run --rm flash     # needs USB passthrough — see docker-compose.yml's header comment
docker compose run --rm monitor
```

First build needs internet access once — `main/idf_component.yml` pulls
in Espressif's `mdns` component from the registry (it moved out of core
ESP-IDF as of the v5.2.x line, so it's no longer bundled).

The dev container itself has no device access on purpose (a hard-coded
device mount breaks container creation on Windows, where there's no real
`/dev` for Docker Desktop to bind from) — flash and monitor from the host,
or from a plain terminal using the `docker compose` commands above with
USB passthrough set up.

Or flash from the host directly (`pip install esptool`), which sidesteps
USB passthrough entirely:

```bash
scripts/flash.sh /dev/ttyUSB0     # or COM5 on Windows
scripts/monitor.sh /dev/ttyUSB0
```

**Hardware note:** USB Serial/JTAG is native on GPIO19/GPIO20 via the
USB-C connector — no external programmer or probe needed, for flashing or
for OpenOCD debugging (`openocd -f board/esp32s3-builtin.cfg`).

### First boot / WiFi setup

With no WiFi credentials stored, the device starts a SoftAP:

```
SSID:     GrowBox-Setup
Password: growbox123
URL:      http://192.168.4.1
```

Connect, open the URL, enter your WiFi credentials. Device restarts,
connects, and the dashboard becomes reachable at `http://growbox.local`.

---

## Power budget

Estimated power at different LED brightness levels:

| Brightness | LED power | Total estimated wall draw |
|---|---|---|
| 40% | 34.8W | ~40W |
| 50% | 43.5W | ~49W |
| 65% | 56.6W | ~62W |
| 75% | 65.3W | ~70W |
| 85% | 74.0W | ~79W |
| 100% | 87W | ~92W |

## Thermal analysis — LED board cooling

Each LED board dissipates 21.76W at 100% brightness (20× XL-3030WWC-1W-3V,
1.088W each — see [LED Panel Board](#3-led-panel-board)) through an 85×55mm
single-layer FR4 board with an aluminum bottom layer, no separate bolted-on
plate. That's roughly 4.6W/cm² of board area, which is a lot of heat flux
for passive cooling at that footprint — hence the heatsink + fan retrofit
(2× 20×20×80mm extruded aluminum heatsinks per board, each pasted to the
aluminum backing, each with its own dedicated 5015 blower (24dB) on a
short individual duct — 8 fans total across the 4 boards, one per
heatsink rather than one shared between both — see photo above).

**Disclaimer:** no published thermal-resistance datasheet exists for this
exact XINGLIGHT LED SKU, for a generic 20×20×80mm heatsink, or for this
specific blower/duct combination. The figures below are an engineering
estimate built from the board's real electrical data (this doc) plus
typical thermal-resistance ranges for parts in this class — not a lab
measurement. Validate with a thermocouple or IR thermometer on the real
board before trusting these as hard limits.

**Model:**
```
T_junction = T_ambient + P_board × R_board-to-ambient + (P_board / 20) × R_led(j-to-solderpoint)
```
- R_led(j-sp) ≈ 8–15°C/W (typical for a 1W SMD-3030 package), 12°C/W used as the mid estimate
- T_ambient assumed 30°C cabinet interior — rescale linearly for your measured ambient
- Target ceilings: 125°C = typical absolute Tj max for this LED class (hard limit, not for sustained use); 105°C = recommended sustained limit for reasonable lumen-maintenance/lifetime

| Cooling stage | R_board-ambient (est.) | Max continuous W/board @105°C | Max continuous W/board @125°C | As brightness % |
|---|---|---|---|---|
| Bare board, no heatsink | ~18°C/W (14–24) | ~4W (3–5W) | ~5W (4–7W) | ~18–23% |
| + 2× heatsink, no fan (natural convection) | ~6°C/W (4–9) | ~11W (8–17W) | ~14W (10–22W) | ~50–66% |
| + heatsink + dedicated 5015 blower per heatsink (forced air) | ~2°C/W (1.2–3) | full 21.76W, Tj ≈ 87°C | full 21.76W, Tj ≈ 87°C | 100% |

The bare-board figure confirms the heatsinks weren't optional — without
them the board is thermally limited to roughly a fifth of rated power.
Heatsinks alone roughly triple the safe ceiling but likely still can't
sustain 100% brightness on natural convection. With the fan, heat stops
being the limiting factor at all — the driver's 340mA current-sense
ceiling becomes the real limit instead.

**Geometry note:** each heatsink gets its own dedicated blower on its own
short duct rather than two heatsinks sharing a single fan in series — so
unlike a shared-duct layout, there's no downstream heatsink breathing air
that's already been pre-heated by an upstream one. Both heatsinks on a
board run symmetrically, each fed with fresh ambient air, so the ~87°C
estimate above applies evenly rather than being concentrated at one hot
spot. The main residual uncertainty is the fans themselves — 24dB 5015
blowers are a quiet, lower-airflow variant of that form factor (typical
full-speed 5015s are rated closer to 35–45dB), so the ~2°C/W forced-air
estimate assumes they still move enough air to land in that range; worth
confirming with the same thermocouple check as the other rows.

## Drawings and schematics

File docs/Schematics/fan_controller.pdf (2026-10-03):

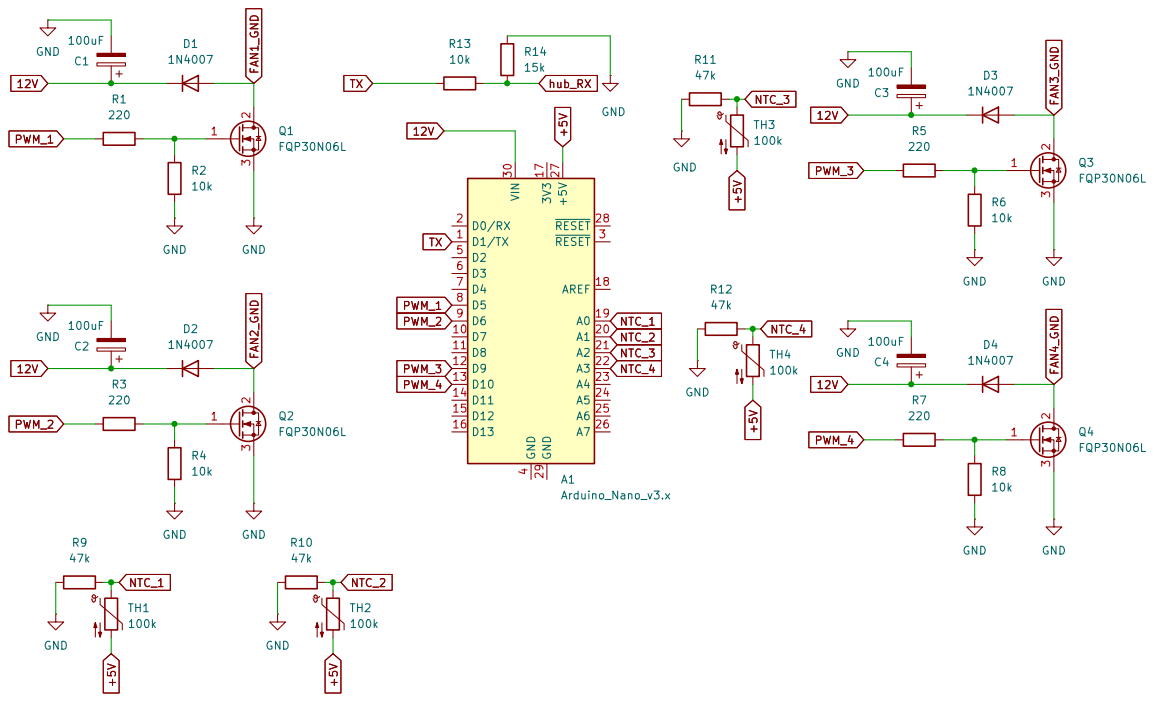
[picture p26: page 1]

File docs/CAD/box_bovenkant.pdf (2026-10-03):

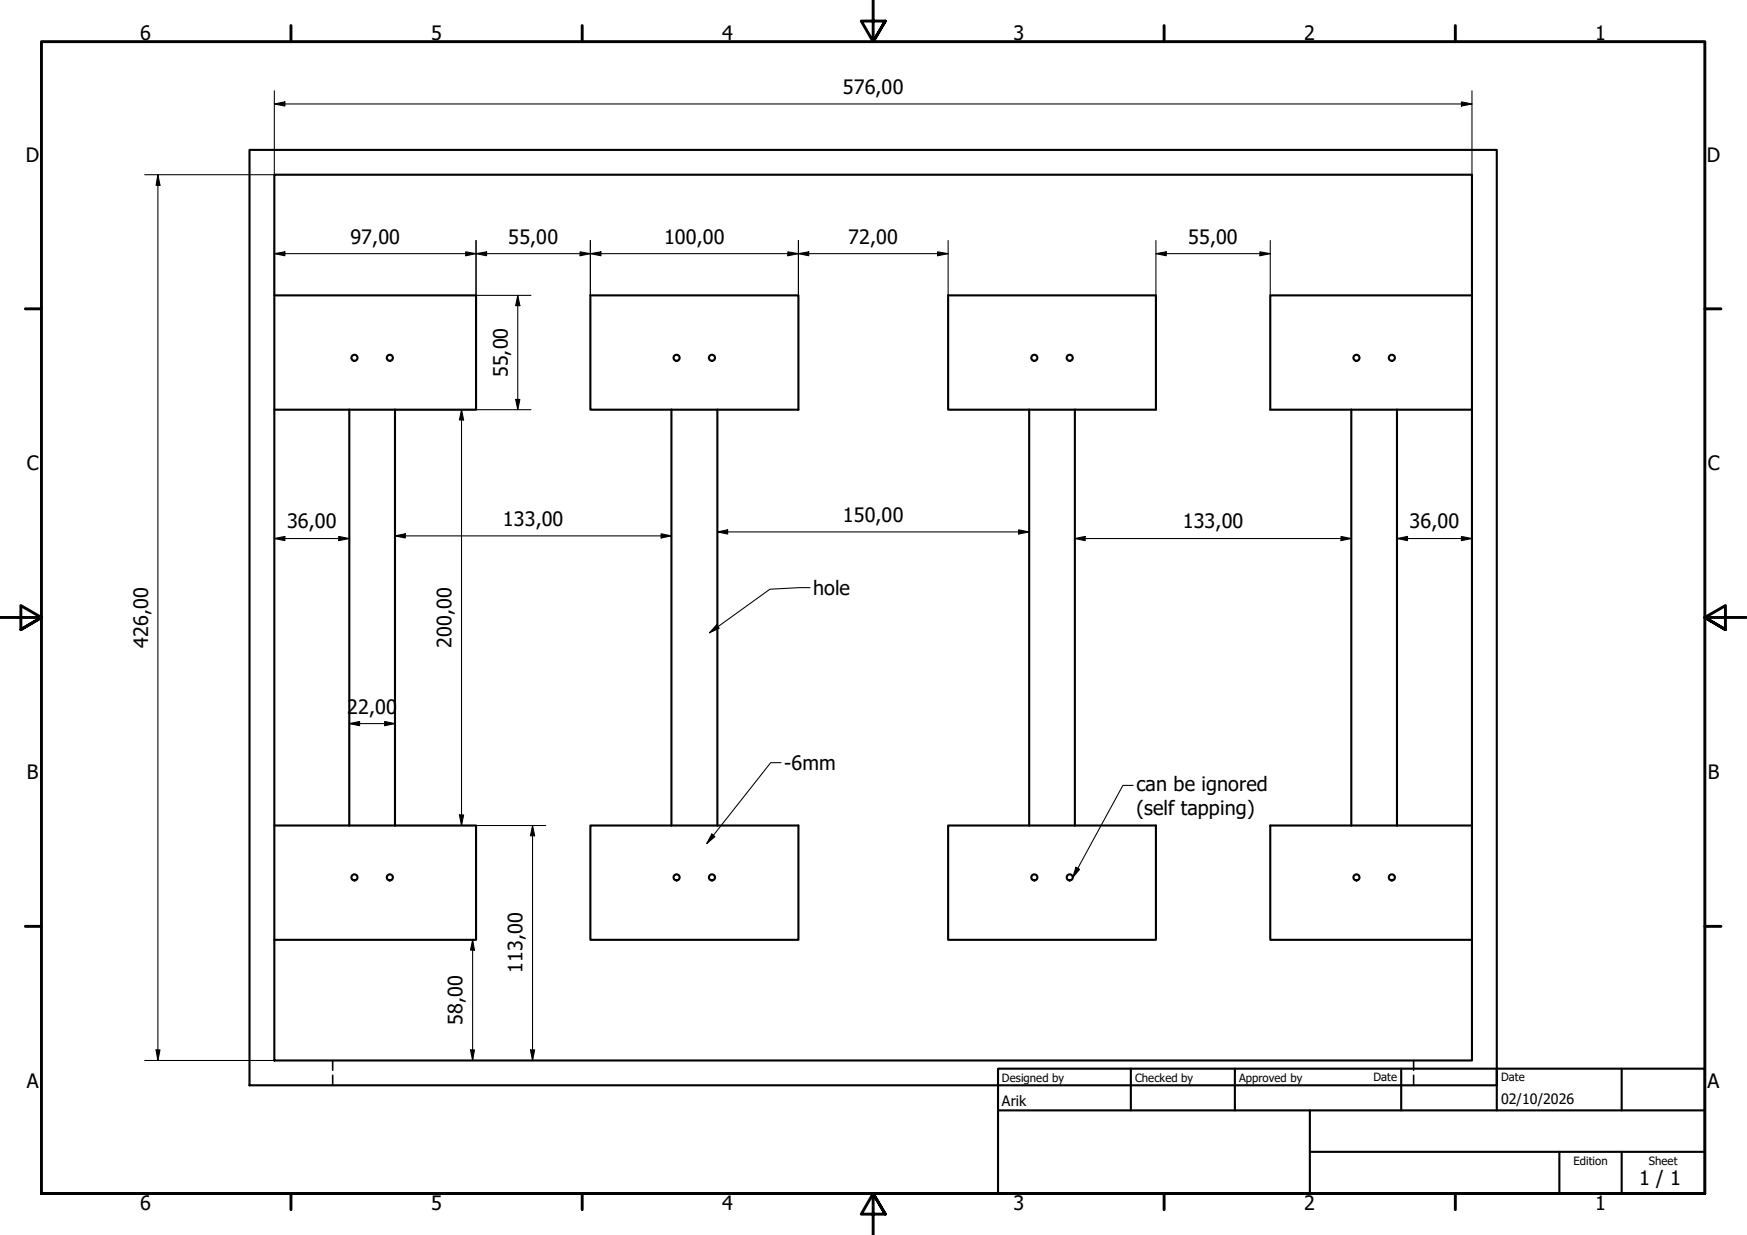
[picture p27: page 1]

can be ignored
(self tapping)

Designed by | Checked by | Approved by Date | Date 02/10/2026
Arik

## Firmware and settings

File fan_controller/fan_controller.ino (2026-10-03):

/* GrowBox LED cooling fan controller — Arduino Nano
 * Arik Nel
 * Independent thermal safety loop for the 8x 5015 blowers cooling the LED
 * heatsinks (see ../BUILD.md#thermal-analysis--led-board-cooling). Runs on
 * its own Nano specifically so fan control keeps working even if the
 * ESP32-S3 hub or ESP32-CAM hang, crash, or are mid-reboot — it has no
 * dependency on either board.
 *
 * 4 independent zones, one per LED board: each zone has its own NTC
 * (mounted directly on that board's PCB, not on a heatsink, so it reads
 * that specific board's temperature rather than general airflow) and its
 * own MOSFET switching that board's 2 fans together. A board running
 * hotter than the other 3 only speeds up its own fans, not all 8 — unlike
 * a single shared-output design, one board with worse airflow doesn't
 * drag the other three's fans up with it.
 *
 * Wiring (x4, one set per zone):
 *   NTC analog input — voltage divider:
 *     5V --- NTC --- (node, to Nano Ax) --- SERIES_RESISTOR_OHMS --- GND
 *   MOSFET gate — Nano PWM pin, through a ~220ohm series resistor, to a
 *     logic-level N-channel MOSFET gate (e.g. IRLZ44N). MOSFET source to
 *     GND, drain to that board's 2 fans' common return; fans' + goes
 *     straight to the 12V rail. Add a ~10k gate pull-down resistor (gate
 *     to GND) on each MOSFET so it defaults OFF (not floating) during
 *     Nano power-on/reset, before setup() takes over — a floating gate
 *     can sit the MOSFET in its lossy linear region and overheat it,
 *     which matters more here than losing a few hundred ms of cooling.
 *
 * Reports to the hub over the same hardware Serial used for USB upload
 * (Nano pins 0/RX, 1/TX) — wired to the ESP32-S3 hub's J14 UART0 debug
 * header (hub TX->Nano RX not needed, this is send-only: the hub never
 * talks back). That header carries nothing else — the hub flashes over
 * native USB and its console goes out over USB-Serial-JTAG, not UART0, so
 * it's free. Unplug this link before re-uploading the sketch over USB, same
 * as unplugging anything else wired to pins 0/1.
 *
 * Needs a voltage divider on that line — the Nano is 5V logic, the
 * ESP32-S3's GPIOs are 3.3V max. Nano TX --[10k]-- (node) --[15k]-- GND,
 * node to hub RX: 5V x 15k/(10k+15k) = 3.0V, safely above the ESP32's
 * logic-high threshold and under its 3.3V max. See fan_controller/README.md
 * for the diagram.
 *
 * No external libraries required — stock Arduino IDE, board "Arduino
 * Nano", upload like any sketch.
 */

#include <Arduino.h>

/* ---------------- configuration ---------------- */

#define NUM_ZONES 4

/* zone index 0..3 = LED board 1..4 — keep this order consistent with
 * however the boards are physically labeled in the cabinet, so "zone 2
 * running hot" on the serial log actually points at the right board. */
const uint8_t SENSOR_PINS[NUM_ZONES] = { A0, A1, A2, A3 };
const uint8_t FAN_PWM_PINS[NUM_ZONES] = { 5, 6, 9, 10 };

/* NTC voltage divider: 5V -> NTC -> (sense node) -> SERIES_RESISTOR -> GND.
 * Part on hand: HNTC-104F3950FB, 100k @25C, B=3950, +/-1% (LCSC C52204613).
 * 47k series resistor centers the divider reasonably across the 35-55C fan
 * curve (~327/1023 at 25C, ~626/1023 at 55C) — change it here if the real
 * build ends up using a different value. */
#define SERIES_RESISTOR_OHMS 47000.0
#define NTC_NOMINAL_OHMS     100000.0
#define NTC_NOMINAL_C        25.0
#define NTC_BETA             3950.0
#define ADC_MAX               1023.0

/* Fan speed curve, per zone. Below FAN_START_C that zone's fans are fully
 * off; duty ramps linearly from MIN_DUTY at FAN_START_C to 255 (full) at
 * FAN_FULL_C and stays at full above that. FAN_OFF_HYST_C keeps the curve
 * from chattering right at the start threshold. On-PCB NTCs read closer to
 * the actual board temperature than a heatsink-mounted sensor would, but
 * these numbers are still placeholders — tune them against a real
 * thermocouple on the board, same as every other number in the thermal
 * analysis this design is based on. */
#define FAN_START_C   35.0
#define FAN_FULL_C    55.0
#define FAN_OFF_HYST_C 3.0
#define FAN_MIN_DUTY   90   /* out of 255 — enough to spin a small blower reliably, not stall at a too-low PWM duty */

/* A sensor reading this far outside a plausible range (wiring fault, open
 * circuit, short) is treated as a FAILURE for that zone, not as "cold" —
 * that zone fails toward fans-on, not fans-off, since this is a cooling
 * safety loop. Other zones are unaffected. */
#define SENSOR_FAULT_LOW_C  -20.0
#define SENSOR_FAULT_HIGH_C 120.0

#define SERIAL_BAUD        9600
#define REPORT_INTERVAL_MS 2000
#define SAMPLE_INTERVAL_MS 500

/* Matches the JSON-line-over-UART convention already used for the hub<->cam
 * link (see ../firmware/main/uart_cam.c) — one line, newline-terminated.
 * A faulted sensor reports as JSON null rather than a made-up number. */
void reportToHub(float temps[NUM_ZONES], uint8_t duties[NUM_ZONES])
{
    Serial.print(F("{\"temps\":["));
    for (uint8_t z = 0; z < NUM_ZONES; z++) {
        if (isnan(temps[z])) Serial.print(F("null"));
        else Serial.print(temps[z], 1);
        if (z < NUM_ZONES - 1) Serial.print(',');
    }
    Serial.print(F("],\"duty\":["));
    for (uint8_t z = 0; z < NUM_ZONES; z++) {
        Serial.print(duties[z]);
        if (z < NUM_ZONES - 1) Serial.print(',');
    }
    Serial.println(F("]}"));
}

/* ---------------- state ---------------- */

bool zoneFansRunning[NUM_ZONES] = { false, false, false, false };
unsigned long lastSampleMs = 0;
unsigned long lastReportMs = 0;

float readTempC(uint8_t pin)
{
    int raw = analogRead(pin);

    /* Open circuit (NTC unplugged) reads near ADC_MAX; a dead short reads
     * near 0 — both are physically impossible real temperatures, so they're
     * the easy case to catch before the Steinhart-Hart math produces a
     * plausible-looking but meaningless number. */
    if (raw <= 1 || raw >= (int)ADC_MAX - 1) {
        return NAN;
    }

    float resistance = SERIES_RESISTOR_OHMS * (ADC_MAX / (float)raw - 1.0);

    /* Simplified beta equation (Steinhart-Hart with only the beta term) —
     * accurate enough for a fan-curve input, not lab-grade calibration. */
    float steinhart = resistance / NTC_NOMINAL_OHMS;
    steinhart = log(steinhart);
    steinhart /= NTC_BETA;
    steinhart += 1.0 / (NTC_NOMINAL_C + 273.15);
    steinhart = 1.0 / steinhart;
    steinhart -= 273.15;

    if (steinhart < SENSOR_FAULT_LOW_C || steinhart > SENSOR_FAULT_HIGH_C) {
        return NAN;
    }
    return steinhart;
}

uint8_t dutyForZone(uint8_t zone, float tempC)
{
    /* NAN means this zone's sensor is faulty — fail safe to full speed
     * for this zone only, rather than trusting a bogus "cold" reading. */
    if (isnan(tempC)) {
        zoneFansRunning[zone] = true;
        return 255;
    }

    float startThreshold = zoneFansRunning[zone] ? (FAN_START_C - FAN_OFF_HYST_C) : FAN_START_C;

    if (tempC < startThreshold) {
        zoneFansRunning[zone] = false;
        return 0;
    }
    zoneFansRunning[zone] = true;

    if (tempC >= FAN_FULL_C) return 255;

    float span = FAN_FULL_C - FAN_START_C;
    float frac = (tempC - FAN_START_C) / span;
    if (frac < 0) frac = 0;
    int duty = FAN_MIN_DUTY + (int)(frac * (255 - FAN_MIN_DUTY));
    if (duty > 255) duty = 255;
    if (duty < FAN_MIN_DUTY) duty = FAN_MIN_DUTY;
    return (uint8_t)duty;
}

void setup()
{
    Serial.begin(SERIAL_BAUD);
    for (uint8_t z = 0; z < NUM_ZONES; z++) {
        pinMode(FAN_PWM_PINS[z], OUTPUT);
        analogWrite(FAN_PWM_PINS[z], 0); /* fans off until the first real reading */
    }
    Serial.println(F("GrowBox fan controller starting — 4 independent zones"));
}

void loop()
{
    unsigned long now = millis();
    if (now - lastSampleMs < SAMPLE_INTERVAL_MS) return;
    lastSampleMs = now;

    float temps[NUM_ZONES];
    uint8_t duties[NUM_ZONES];

    for (uint8_t z = 0; z < NUM_ZONES; z++) {
        temps[z] = readTempC(SENSOR_PINS[z]);
        duties[z] = dutyForZone(z, temps[z]);
        analogWrite(FAN_PWM_PINS[z], duties[z]);
    }

    if (now - lastReportMs >= REPORT_INTERVAL_MS) {
        lastReportMs = now;
        reportToHub(temps, duties);
    }
}

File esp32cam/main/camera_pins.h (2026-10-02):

#pragma once

/* AI-Thinker ESP32-CAM pin mapping — the standard layout used by the
 * common AI-Thinker board and most compatible clones. If frames come back
 * garbled or esp_camera_init() fails, double-check these against your
 * specific board's silkscreen; cheap clones occasionally differ. */

#define CAM_PIN_PWDN   32
#define CAM_PIN_RESET  -1
#define CAM_PIN_XCLK    0
#define CAM_PIN_SIOD   26
#define CAM_PIN_SIOC   27
#define CAM_PIN_D7     35
#define CAM_PIN_D6     34
#define CAM_PIN_D5     39
#define CAM_PIN_D4     36
#define CAM_PIN_D3     21
#define CAM_PIN_D2     19
#define CAM_PIN_D1     18
#define CAM_PIN_D0      5
#define CAM_PIN_VSYNC  25
#define CAM_PIN_HREF   23
#define CAM_PIN_PCLK   22

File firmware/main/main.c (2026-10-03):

#include "esp_log.h"
#include "driver/i2c.h"
#include "freertos/FreeRTOS.h"
#include "freertos/task.h"

#include "state.h"
#include "nvs_config.h"
#include "auth.h"
#include "aht20.h"
#include "fusb302_pd.h"
#include "led_control.h"
#include "schedule.h"
#include "wifi_manager.h"
#include "uart_cam.h"
#include "uart_fan.h"
#include "http_server.h"

static const char *TAG = "main";

#define I2C_PORT       I2C_NUM_0
#define I2C_SDA_GPIO   8
#define I2C_SCL_GPIO   9
#define I2C_FREQ_HZ    400000

#define SENSOR_POLL_INTERVAL_MS 10000

static esp_err_t i2c_bus_init(void)
{
    i2c_config_t conf = {
        .mode = I2C_MODE_MASTER,
        .sda_io_num = I2C_SDA_GPIO,
        .scl_io_num = I2C_SCL_GPIO,
        .sda_pullup_en = GPIO_PULLUP_ENABLE,
        .scl_pullup_en = GPIO_PULLUP_ENABLE,
        .master.clk_speed = I2C_FREQ_HZ,
    };
    esp_err_t err = i2c_param_config(I2C_PORT, &conf);
    if (err != ESP_OK) return err;
    return i2c_driver_install(I2C_PORT, conf.mode, 0, 0, 0);
}

static void sensor_task(void *arg)
{
    for (;;) {
        float t, h;
        if (aht20_read(&t, &h) == ESP_OK) {
            state_lock();
            g_state.temp_c = t;
            g_state.humidity_pct = h;
            g_state.sensor_valid = true;
            if (t < g_state.temp_min) g_state.temp_min = t;
            if (t > g_state.temp_max) g_state.temp_max = t;
            if (h < g_state.humidity_min) g_state.humidity_min = h;
            if (h > g_state.humidity_max) g_state.humidity_max = h;
            state_unlock();
        } else {
            ESP_LOGW(TAG, "AHT20 read failed");
        }
        vTaskDelay(pdMS_TO_TICKS(SENSOR_POLL_INTERVAL_MS));
    }
}

void app_main(void)
{
    ESP_ERROR_CHECK(nvs_config_init());
    state_init();
    ESP_ERROR_CHECK(auth_init());

    if (wifi_manager_needs_provisioning()) {
        ESP_LOGW(TAG, "no WiFi credentials stored, starting provisioning portal");
        wifi_manager_run_provisioning(); /* never returns */
        return;
    }

    ESP_ERROR_CHECK(i2c_bus_init());
    ESP_ERROR_CHECK(aht20_init(I2C_PORT));
    ESP_ERROR_CHECK(led_control_init());
    ESP_ERROR_CHECK(schedule_init());
    ESP_ERROR_CHECK(uart_cam_init());
    uart_cam_task_start(4, 1);
    ESP_ERROR_CHECK(uart_fan_init());
    uart_fan_task_start(3, 1);
    pd_task_start(I2C_PORT, 5, 0);
    xTaskCreatePinnedToCore(sensor_task, "sensor_task", 2048, NULL, 3, NULL, 0);

    ESP_ERROR_CHECK(wifi_manager_start_station());
    ESP_ERROR_CHECK(http_server_start());

    ESP_LOGI(TAG, "microgrowery controller boot complete");
}

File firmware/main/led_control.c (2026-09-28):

#include "esp_log.h"
#include "driver/ledc.h"
#include "led_control.h"
#include "nvs_config.h"
#include "state.h"

static const char *TAG = "led_control";

#define LEDC_TIMER_RES   LEDC_TIMER_10_BIT
#define LEDC_FREQ_HZ     25000
#define LEDC_DUTY_MAX    1023

#define LEDC_CH_LED   LEDC_CHANNEL_0
#define LEDC_CH_FAN1  LEDC_CHANNEL_1
#define LEDC_CH_FAN2  LEDC_CHANNEL_2

static uint32_t percent_to_duty(uint8_t percent)
{
    if (percent > 100) percent = 100;
    return (uint32_t)(((uint32_t)percent * LEDC_DUTY_MAX) / 100);
}

static esp_err_t set_channel_duty(ledc_channel_t channel, uint8_t percent)
{
    uint32_t duty = percent_to_duty(percent);
    esp_err_t err = ledc_set_duty(LEDC_LOW_SPEED_MODE, channel, duty);
    if (err != ESP_OK) return err;
    return ledc_update_duty(LEDC_LOW_SPEED_MODE, channel);
}

esp_err_t led_control_init(void)
{
    ledc_timer_config_t timer_cfg = {
        .speed_mode = LEDC_LOW_SPEED_MODE,
        .duty_resolution = LEDC_TIMER_RES,
        .timer_num = LEDC_TIMER_0,
        .freq_hz = LEDC_FREQ_HZ,
        .clk_cfg = LEDC_AUTO_CLK,
    };
    esp_err_t err = ledc_timer_config(&timer_cfg);
    if (err != ESP_OK) {
        ESP_LOGE(TAG, "ledc_timer_config failed: %s", esp_err_to_name(err));
        return err;
    }

    ledc_channel_config_t channels[3] = {
        {
            .gpio_num = LED_GPIO,
            .speed_mode = LEDC_LOW_SPEED_MODE,
            .channel = LEDC_CH_LED,
            .timer_sel = LEDC_TIMER_0,
            .duty = 0,
            .hpoint = 0,
        },
        {
            .gpio_num = FAN1_GPIO,
            .speed_mode = LEDC_LOW_SPEED_MODE,
            .channel = LEDC_CH_FAN1,
            .timer_sel = LEDC_TIMER_0,
            .duty = 0,
            .hpoint = 0,
        },
        {
            .gpio_num = FAN2_GPIO,
            .speed_mode = LEDC_LOW_SPEED_MODE,
            .channel = LEDC_CH_FAN2,
            .timer_sel = LEDC_TIMER_0,
            .duty = 0,
            .hpoint = 0,
        },
    };
    for (int i = 0; i < 3; i++) {
        err = ledc_channel_config(&channels[i]);
        if (err != ESP_OK) {
            ESP_LOGE(TAG, "ledc_channel_config[%d] failed: %s", i, esp_err_to_name(err));
            return err;
        }
    }

    uint8_t led_pct = 70, fan1_pct = 50, fan2_pct = 60;
    nvs_config_get_u8("led_brightness", &led_pct, 70);
    nvs_config_get_u8("fan1_speed", &fan1_pct, 50);
    nvs_config_get_u8("fan2_speed", &fan2_pct, 60);

    led_set_brightness(led_pct);
    fan_set_speed(1, fan1_pct);
    fan_set_speed(2, fan2_pct);

    return ESP_OK;
}

float led_watts_for(uint8_t percent)
{
    if (percent > 100) percent = 100;
    return ((float)percent / 100.0f) * LED_PANEL_MAX_WATTS;
}

esp_err_t led_set_brightness(uint8_t percent)
{
    if (percent > 100) percent = 100;
    esp_err_t err = set_channel_duty(LEDC_CH_LED, percent);
    if (err != ESP_OK) return err;

    state_lock();
    g_state.led_brightness = percent;
    state_unlock();

    return nvs_config_set_u8("led_brightness", percent);
}

esp_err_t fan_set_speed(uint8_t fan_id, uint8_t percent)
{
    if (percent > 100) percent = 100;
    ledc_channel_t channel = (fan_id == 1) ? LEDC_CH_FAN1 : LEDC_CH_FAN2;
    esp_err_t err = set_channel_duty(channel, percent);
    if (err != ESP_OK) return err;

    state_lock();
    if (fan_id == 1) g_state.fan1_speed = percent;
    else g_state.fan2_speed = percent;
    state_unlock();

    return nvs_config_set_u8(fan_id == 1 ? "fan1_speed" : "fan2_speed", percent);
}

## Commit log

2026-09-28 Update images in README for LED board
2026-09-28 Update sensor images in README.md
2026-10-02 esp32cam and few bug fixes
    [camera.c, camera_pins.h, http_server.c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]
2026-10-02 flash LED control
2026-10-02 added camera shell
2026-10-02 removed wifi, pure uart cam
2026-10-02 esp32cam stl
    [ESP32CAM MOUNT.ipt, mount.stl]
2026-10-02 cam freeze frame
2026-10-03 added fan controller
    [Radial-Cooling-Fan-5015-DC12V.SLDASM, Radial-Cooling-Fan-5015-DC12V.STEP, Radial-Cooling-Fan-5015-DC12V.ipt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]
2026-10-03 UART to nano
2026-10-03 updated schematic, added UART communication, added voltage divider (3.0V
2026-10-05 added pcb image and driver schematic
